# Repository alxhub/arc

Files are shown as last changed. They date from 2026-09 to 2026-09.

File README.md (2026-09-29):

# ARC — model railroad control

ARC is my hobby ecosystem of model railroad control systems. It is designed as an integrated, full stack system, from the computer running the layout to the boards powering track districts, moving turnouts, and lighting signal masts.

The design emphasizes global processing and specialized boards for dedicated tasks. A layout computer knows the track plan and coordinates the whole railroad, while distributed hardware provides the power, sensing, and local control each task needs. This gives the software a layout-wide view while keeping physical connections close to the equipment they serve.

ARC is designed for evolving and temporary layouts, with plug-and-play operation as a guiding goal. Common capabilities are available throughout the system, so changing the track plan can be an ordinary part of using the railroad. That flexibility goes hand in hand with intelligent control: the computer can use its knowledge of track connections and turnout positions to prepare the hardware for a route.

This repository contains ARC's schematics written in [Stackup](https://github.com/stackup-eda/stackup) and the corresponding KiCad PCB projects. Stackup is another of my projects: a declarative language and toolchain for describing electronic circuits as text. It expresses parts, reusable circuits, connections, and design constraints, checks them together, and exports the result for KiCad. Stackup uses KDL as its file syntax, which is why the schematic sources have a `.kdl` extension.

The architecture and intended system behavior are described below; individual board READMEs cover their roles and design decisions. [Control architecture](CONTROL.md) describes the administrative, operations, control, and field planes, including district policy and PSU authority on loss of communication. [ARC CAN protocol](PROTOCOL.md) defines the wire format and node identity scheme.

## Three levels of control

ARC organizes the layout into three levels:

1. **The layout computer**, usually a Raspberry Pi, knows the track plan, runs the layout, and coordinates its behavior. The ARC HAT connects the Pi to the backbone and provides control of the layout's master contactor.
2. **The ARC-Link backbone** connects primary functional boards, including DCC district drivers and Trackside Hubs, over CAN. These boards typically live together in one or more clusters around the layout and are DIN-rail mountable.
3. **Trackside bus legs** extend from those clusters along the rails. They connect boards that serve a local purpose, such as a signal mast, turnout, servo, or vehicle tag reader.

A **Trackside Hub is a backbone board** that connects these last two levels. It receives commands over ARC-Link and manages up to three separate trackside bus legs, using LIN for local signaling. This arrangement lets the backbone connect clusters of functional hardware while the trackside wiring follows the railroad to individual accessories.

## Power and installation

ARC is designed for industrial DC power supplies: **12 V for N scale** and **15 V for HO scale**, with a particular emphasis on DIN-rail mounted supplies. Primary backbone boards share that mounting approach, making it practical to assemble a cluster of power and control hardware together.

The power architecture distinguishes the supply carried by ARC-Link from the power delivered to the rails and accessories. The supply board switches power onto ARC-Link; district drivers and Trackside Hubs also have their own connections to the layout's supply for their loads. District drivers generate rail power locally from the shared DCC timing signal.

## ARC-Link: the backbone

ARC-Link carries power, CAN communication, and DCC synchronization over **eight-wire Ethernet cable**:

| Conductors | Purpose |
| --- | --- |
| 2 | Backbone power |
| 2 | Backbone ground |
| 2 | CAN differential pair for commands and status |
| 2 | DCC differential pair for synchronized track timing |

Ethernet cable is the wiring medium; ARC-Link uses CAN for communication. The separate DCC pair carries timing, not the traction current delivered to the rails. The supply board normally generates that timing, and district drivers use it to produce their individual DCC outputs.

**Ground loop isolation is a central design priority.** The supply board establishes the backbone's ground reference, and other active backbone boards isolate their local circuits from the link. This separates the backbone reference from local track supply returns and control wiring as the system extends between clusters around the layout.

ARC-Link is distinct from LCC. Support for LCC devices is planned through a dedicated **ARC ↔ LCC bridge**, allowing those devices to participate in the layout alongside ARC hardware.

## The trackside bus

The trackside bus uses **four-wire telephone cable with RJ-11 connectors**. Each leg carries four connections:

| Conductor | Purpose |
| --- | --- |
| Track voltage | The layout's track-voltage supply for local loads |
| 5 V | Low-voltage power |
| Ground | Local power and signaling return |
| LIN | Commands and status for trackside boards |

These legs typically parallel the rails, keeping accessory wiring near the devices it serves. A signal controller can sit near its mast, a turnout controller near its turnout machines, and a tag reader near its separate antenna flex.

Each Trackside Hub manages up to three legs and can switch them independently. Its backbone connection crosses an isolation boundary; the trackside legs share the hub's local power and return.

## A dedicated output for every district

ARC calls a track block a **district** and standardizes on a distinct, independently controlled power feed for each one. The system is optimized for many separate outputs, with district boards providing four, six, or eight outputs per board. This makes each district a unit of power control, sensing, and fault handling.

Every district is designed to include the same core capabilities:

- **Built-in block detection through drive-current sensing.** This detects locomotives, but does not detect resistive wheelsets.
- **Built-in autoreversing.** Each district can reverse its output phase as needed for reversing track arrangements, including advance changes coordinated by the layout computer.
- **Programming-track operation on demand.** Any district can serve as a fully featured programming track when needed, with a separate programming signal and a lower current limit.
- **Independent control and fault reporting.** Each output can be switched and monitored separately, so a fault can be identified and handled at the affected district.

These capabilities are part of the district design rather than separate accessories to add to selected sections. A district's role can change with the layout's needs, including switching between normal running and programming operation.

## Layouts that evolve, control that understands them

Having autoreversing available in every district makes it easier to experiment with the track plan. Add a reversing loop on a whim, and the surrounding districts already have the phase control they need: there is no need to carefully rewire them around a specially designated reversing output. Dedicated district feeds and a controller that knows the revised track plan provide the basis for this plug-and-play approach.

That global picture also enables proactive polarity control. ARC is designed to use the track plan and turnout configurations to align district polarities automatically before wheels cross a boundary and cause a short. The layout computer can coordinate the outputs involved in a route because it knows how those sections connect.

The Kato turntable controller is another example of this intended behavior. As the turntable spins, ARC can use its knowledge of the table's position and connecting tracks to align their polarities automatically. The specialized board operates the turntable, while the layout-wide picture makes coordinated track power possible.

## Backbone boards

| Board | Role |
| --- | --- |
| [ARC-PSU-01](backbone/psu-01/README.md) | Switches power onto ARC-Link and normally generates DCC timing. |
| [ARC-HAT-01](backbone/hat-01/README.md) | Connects a Raspberry Pi to CAN and controls the layout contactor. |
| [ARC-EX-ARC](backbone/ex-arc/README.md) | Connects a CommandStation-EX and its motor shield to ARC. |
| [ARC-TERM-01](backbone/term-01/README.md) | Terminates the CAN and DCC pairs at the end of a run. |
| [ARC-DST-01x4 rev 2](backbone/dst-01x4/README.md) | Drives four independent track districts. |
| [ARC-DST-01x6](backbone/dst-01x6/README.md) | Drives six independent track districts. |
| [ARC-DST-01x8](backbone/dst-01x8/README.md) | Drives eight independent track districts. |
| [ARC-YRD-01x8](backbone/yrd-01x8/README.md) | Controls yard turnouts and signal lamps. |
| [ARC-TRK-HUB-01](backbone/trk-hub-01/README.md) | Bridges backbone CAN to three trackside LIN runs. |

## Trackside boards

| Board | Role |
| --- | --- |
| [ARC-TRK-LED-01](trackside/trk-led-01/README.md) | Drives signal lamps on a LIN run. |
| [ARC-TRK-SRV-01](trackside/trk-srv-01/README.md) | Drives servos, sound, and a signal head. |
| [ARC-TRK-NFC-01](trackside/trk-nfc-01/README.md) | Reads vehicle tags with a separate antenna. |
| [ARC-TRK-ANT-01](trackside/trk-ant-01/README.md) | Provides the reader's flexible track antenna. |
| [ARC-TRK-TRN-01](trackside/trk-trn-01/README.md) | Operates four turnout machines. |
| [ARC-TRK-TBL-01xK](trackside/trk-tbl-01xK/README.md) | Operates a Kato turntable. |

## Firmware

The [Rust firmware workspace](firmware/README.md) uses Embassy. It contains the
shared ARC-Link protocol crate at `firmware/shared/link`, the shared DCC packet
and waveform generator at `firmware/shared/dcc`, the `dst-01` board
crate for x4 rev1/rev2, and the `psu-01` board crate for link power, a
bounded locomotive table, and DCC idle and speed packets. DST rev1 includes the
same transmitter, disabled at boot. PSU and DST rev1 both require
[CAN transmit permission](PROTOCOL.md#dcc-control-message-0x01-grant), retained until
the source restarts. Once the expected layout is good, layoutd selects one master
and grants permission. PSU link power and CAN discovery start independently of DCC.
All current firmware targets also use an Embassy bootloader and a shared
[CAN FD update protocol](PROTOCOL.md#firmware-update-over-can-fd) for staged
application updates.

## Layout software

The first host-side service is [layoutd](services/layoutd/README.md). It owns
retained MQTT facts about track nodes, derives and checks the layout graph
against observed CAN node identities, and publishes overall status. Its CAN interface supports file snapshots and the virtual CAN bus for development
and tests. It selects the DCC master only after all expected hardware is accounted for.

The initial [dispatchd](services/dispatchd/README.md) bridge reads district
status and PSU throttle status from the virtual CAN bus, publishes MQTT state
under `/<layout>/district/` and `/<layout>/loco/`, and converts non-retained
locomotive commands to CAN throttle-set frames. PSU and DST rev1 share the
locomotive table and require the transmit grant assigned by layoutd.

The [virtual CAN lab](sim/README.md) builds the DST-01x4 firmware crate as host
binaries for both board revisions and connects them over a simulated CAN bus.
Its world clock starts paused; tests advance it explicitly so CAN arbitration,
PSU and district timers, DCC delivery, track motion, and current sampling share
the same time. The physical track fixture is separate from layoutd's configured
layout, allowing tests to exercise unknown or incorrect track plans.

## Working with the designs

The boards are composed from reusable Stackup circuits in [`shared/`](shared/). Each board directory keeps its `board.kdl`, supporting Stackup sources, functional README, and KiCad PCB project together.

The designs import the [Stackup parts library](https://github.com/stackup-eda/library), pinned in `manifest.kdl`. For local development, add a `manifest.local.kdl` with a path to a parts checkout:

```kdl
library stackup path="../stackup-parts"
```

Run `stackup check backbone/psu-01/board.kdl` to validate a board. Substitute any other board's `board.kdl` path as needed. Use `--locked` to check against the pinned library commit. Without a local override, the CLI fetches Git libraries into `.stackup/cache/` beside `manifest.kdl`.

Each KiCad PCB has a `.stackup_sch` sidecar pointing to the adjacent `board.kdl`. To sync a closed board with the Stackup KiCad plugin, using KiCad's bundled Python (`STACKUP_KDL` is the path to the Stackup worktree):

```sh
/Applications/KiCad/KiCad.app/Contents/Frameworks/Python.framework/Versions/3.9/bin/python3 \
  "$STACKUP_KDL/kicad-plugin/sync_headless.py" \
  backbone/term-01/term-01.kicad_pcb
```

The PCB layouts retain their routed copper and KiCad project settings. Some newer parts in the district and yard schematics still need placement and routing. A Stackup check or PCB sync is not a DRC or fabrication signoff. The antenna board retains an older footprint table as `fp-lib-table.legacy` for reference; KiCad uses its existing `fp-lib-table`.

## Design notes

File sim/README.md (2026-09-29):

# Virtual CAN lab

This lab runs the actual `psu-01` firmware core and the `dst-01` firmware crate
as host binaries, with one district node for each DST-01x4 revision. The nodes use the shared `link` codec to publish the
Presence and periodic or state-change district status frames in [PROTOCOL.md](../PROTOCOL.md),
receive district configuration frames, and run the same four district
controllers as the embedded build. A portable user-space bus carries CAN IDs and
CAN FD payload bytes between independent processes.

Start a bus and two nodes with Docker Compose:

```sh
docker compose -f sim/compose.yaml up --build
```

Compose starts the clock at zero and leaves it paused. Advance it through the
world control port with `{"op":"advance","milliseconds":100}`; no firmware
timer or CAN batch progresses while it is paused.

Node A builds with `host,rev1` and node B with `host,rev2`. PSU-01 closes the
simulated link switch after its monitor responds and qualifies 15 V. It waits
for a CAN transmit grant before starting the `FF 00 FF` DCC idle stream. Run
layoutd against the virtual CAN bus with all three boards in its retained layout
to select and grant a master. The district nodes validate the packet
bits and each half-bit duration and require both power and recurring packets
before treating the source as ready. Every output remains disabled until
configured over CAN. Logs show identities, peer Presence, and state changes.
The host-only `--network-id` override supports collision
tests.

Run the first automated integration scenario:

```sh
python3 -m sim.scenarios short_recovery
python3 -m sim.scenarios district_config
python3 -m sim.scenarios psu_startup
python3 -m sim.scenarios psu_throttle
python3 -m sim.scenarios moving_loco
python3 -m sim.scenarios phase_bridge
```

Each runner starts an isolated Compose project with the same explicit world
clock, including scenarios that leave the physical track fixture disconnected
from district outputs. The original short-recovery
scenario verifies PSU boots without DCC
permission, explicitly grants PSU using the CAN wire message, and waits for both firmware nodes to
see a peer, configures districts 0 and 1 over CAN, then injects a short into each
revision's district 0,
checks that power is inhibited without disturbing district 1, clears the short,
and waits for normal operation to resume after ten clear probes. It reports the
last observed state and container logs on failure, then tears down its project.
It uses a test-only TCP control port on each host binary; these commands are
not ARC CAN messages and are absent from embedded firmware. The scenarios also
observe status frames on the virtual CAN bus, including windowed current after a
short.
The `district_config` scenario verifies default-disabled outputs, wrong-target
and invalid-state rejection, source-readiness gating, one-output enablement,
programming selection, and explicit disablement.
The `psu_startup` scenario verifies automatic link power, the exact idle packet
and timing, PSU CAN status, district source readiness on both revisions, and
loss of district output after a simulated PSU overvoltage latches the link off.
The `psu_throttle` scenario validates two locomotive entries, immediate CAN
status, idempotent repeat, stale-command rejection, and the DCC speed/stop
packet bytes. Both host and board builds accept valid throttle frames without
an authority exchange; that exchange remains future protocol work.

The `moving_loco` and `phase_bridge` scenarios start a separate physical world from
`sim/world/fixtures/two_districts.json`. This fixture owns actual segment
lengths, endpoint connections and A/B rail mapping, district-output wiring,
and loco placement. It exists independently of `layoutd` and MQTT, so a test
can leave the administrative layout unknown or configure it incorrectly while
the physical system continues to behave. The world receives DCC
packets from the signal bus, passes speed commands only to locos on energized
districts, advances their positions, and gives the DST host current and fault
samples. The scenario checks that CAN current moves from one district to the
other as the loco crosses. A pickup span bridges both outputs near a boundary;
a phase mismatch after accounting for endpoint rail mapping produces a fault
and high current on both powered outputs. `phase_bridge` uses a swapped-rail
fixture and checks that the real DST host controllers trip on both outputs.
Host firmware currently holds phase normal, so automatic phase correction is
not yet exercised.

Run the world outside a scenario with:

```sh
ARC_SIM_WORLD=world:17502 docker compose -f sim/compose.yaml up --build
```

`ARC_SIM_WORLD` connects node A to the physical track fixture;
`ARC_SIM_CAN_CLOCK` puts CAN batches on the world clock; `ARC_SIM_CLOCK`
connects PSU and both DST hosts to that clock. Set `ARC_SIM_CLOCK` for a
separately launched layoutd as well, using `127.0.0.1:17502` from the host.
Runs without `ARC_SIM_WORLD`
use the existing fixed-load district behavior. The world control port is 17502 and accepts one JSON
request per line: `{"op":"status"}`, `{"op":"advance","milliseconds":100}`,
`{"op":"set_turnout","piece":"id","path":"route"}`,
or `{"op":"place","loco":"id","piece":"id","path":"route","offset_mm":10}`.

To exercise collision detection, start the optional third node with a different
UID and node A's ID:

```sh
docker compose -f sim/compose.yaml --profile collision up --build
```

Both nodes with ID `fa5138` report the conflict. Collision recovery is not
implemented.

The CAN transport uses newline-delimited JSON internally; this is not an ARC
wire format. It batches frames for 5 ms and orders each batch by CAN ID for
application tests. In scenario runs the batch boundary is every fifth
logical millisecond, and the clock waits for dispatch before continuing. The
scenario sender uses a test-only queue barrier before advancing time. A separate signal bus broadcasts link power and DCC packets
as their bit sequences and half-bit durations, replaying the latest power
state to nodes that join late. Packet validity and liveness are modeled; analog
edge shape and scheduling jitter are not. CAN acknowledgements, errors, and
bus-off are also not modeled.

The host runner uses an initial board-component model. A DRV8874 model derives
fault and current observations from the applied drive and an injected short;
rev1 uses simulated TCA9534 output, direction, and fault-input registers, while
rev2 uses direct GPIO state. The current and fault behavior is intentionally
coarse. Embedded and host firmware share command decoding and status scheduling;
their HALs remain separate implementations, so hardware register behavior must be
checked against the board design as this model matures.

The physical world has one logical clock, starting at zero. DCC packets, output
samples, status requests, and host scheduling do not advance it. A scenario
advances it explicitly with the `advance` request. Live advances run in 1 ms
ticks. At each tick the clock waits for CAN arbitration when due, PSU firmware,
link-signal delivery, ordered district firmware processes, and every registered
output sample before continuing. This prevents a pickup bridge from being skipped.
PSU power qualification, DCC packet cadence, district source timeout, protection
timers, and current-report windows all use this logical time in world scenarios.
Loco position and world time are repeatable for the same tick-ordered inputs. A valid DCC packet marks
the simulated source active until link power or the signal connection is lost;
the DST host still enforces its own 30 ms packet-liveness timeout using logical
time. Socket and process deadlines only detect stalled participants; they do
not advance simulation time. Scripted fault injection remains future work. The model does not resolve electrical waveform
shape, wheel-by-wheel pickup, inertia, or detailed motor physics.

Run portable simulator tests with:

```sh
python3 -m unittest discover -s sim/tests
cd firmware && cargo test -p link && cargo test -p dst-01 --lib && cargo test -p psu-01 --lib
```

PSU and DST rev1 use the shared boot-lifetime DCC permission latch. Both start
without permission; tests use the actual CAN Grant message. Rev2 ignores grants. Source status
reports capability, permission, and actual output. Power loss inhibits output
without clearing permission; source restart clears permission and the table.

The host-process test starts both DST revisions without a PSU, supplies simulated
link power and a logical clock participant, and checks CAN grant targeting, malformed grants, rev2 rejection,
exact idle packets and half-bit timing, and permission surviving power loss.
Build and run it from the repository root:

```sh
(cd firmware && cargo build -p dst-01 --bin dst-01-host --features x4,host,rev1 --target-dir target/host-rev1)
(cd firmware && cargo build -p dst-01 --bin dst-01-host --features x4,host,rev2 --target-dir target/host-rev2)
ARC_DST_REV1_BIN="$PWD/firmware/target/host-rev1/debug/dst-01-host" \
ARC_DST_REV2_BIN="$PWD/firmware/target/host-rev2/debug/dst-01-host" \
python3 -m unittest sim.tests.test_dst_sync
```

The layoutd integration test runs the real daemon with an isolated Docker MQTT
broker and all three host firmware processes. It checks that an absent expected
board blocks permission, completing the layout selects only PSU, layoutd exit
does not revoke permission, and a source restart clears it. Docker must be running.

```sh
(cd services/layoutd && cargo build)
(cd firmware && cargo build -p psu-01 --bin psu-01-host --features host)
ARC_LAYOUTD_BIN="$PWD/services/layoutd/target/debug/layoutd" \
ARC_PSU_BIN="$PWD/firmware/target/debug/psu-01-host" \
ARC_DST_REV1_BIN="$PWD/firmware/target/host-rev1/debug/dst-01-host" \
ARC_DST_REV2_BIN="$PWD/firmware/target/host-rev2/debug/dst-01-host" \
python3 -m unittest discover -s sim/tests
```

The shared `dcc` tests cover packet encoding, table scheduling, continuous bit
sequencing, and permission lifetime. Timer register behavior, interrupt deadlines,
oscillator tolerance, and physical transceiver timing still need hardware checks.
The current signal bus models packet content and liveness, not electrical driver
contention.

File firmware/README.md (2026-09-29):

# ARC firmware

Rust 2024 with Embassy. Run the commands below from this directory; Cargo loads
the aliases and linker settings from `.cargo/config.toml` here.

- `shared/link` (`link`): `no_std` backbone CAN protocol crate, shared by boards
  and host tools. The [protocol specification](../PROTOCOL.md) defines identity
  and Presence; the identity derivation, Presence, district configuration, and
  district status codecs are implemented.
- `shared/dcc` (`dcc`): `no_std` packet encoder, throttle table, continuous bit
  engine, and optional STM32 timer transmitter shared by PSU and DST rev1.
- `dst-01`: district-board firmware. The only variant is `x4`; select exactly one
  of `rev1` and `rev2`. The orthogonal `host` feature builds the same firmware
  crate as a host process for the [virtual CAN lab](../sim/README.md). There is
  no default hardware selection.
- `psu-01`: STM32C092 firmware for automatic ARC-Link power startup, supervised
  INA226 measurements, DCC idle and 128-step locomotive packets, a bounded
  locomotive table, and CAN Presence/status.
- `arc-boot`: Embassy bootloader for the G0B1 and C092 application partitions.

```sh
cargo build-dst-rev1 --release
cargo build-dst-rev2 --release
cargo build-psu
cargo build-boot-g0b1
cargo build-boot-c092
cargo test -p link
cargo test -p dcc
cargo test -p dst-01 --lib
cargo test -p psu-01 --lib
cargo fmt --all --check
```

The build aliases expand to `cargo build -p dst-01 --target thumbv6m-none-eabi
--no-default-features --features x4,rev1` (or `x4,rev2`). Both MCUs use this target;
the revision feature selects the Embassy chip and its generated linker memory
map. Build revisions separately: `--all-features` cannot represent one board.
Each build writes `target/thumbv6m-none-eabi/release/dst-01`, replacing the previous
revision's artifact. Use `--target-dir target/rev1` or `target/rev2` to retain both.

The workspace default member is `link`, so plain `cargo build` and `cargo test`
work on the host. The toolchain file pins Rust and installs the embedded target.
Commit `Cargo.lock` to keep firmware dependencies reproducible.

### CAN firmware updates

All three embedded targets accept the same [CAN FD firmware update
protocol](../PROTOCOL.md#firmware-update-over-can-fd). It uses Embassy's
`embassy-boot-stm32` bootloader and blocking firmware updater. Bootloader and
application builds now have separate flash regions:

| MCU | Bootloader | Active application | Staging | Boot state |
| --- | --- | --- | --- | --- |
| STM32G0B1RE (DST rev1) | `0x08000000`, 16 KiB | `0x08004000`, 240 KiB | `0x08040000`, 248 KiB | `0x0807e000`, 8 KiB |
| STM32C092CB (DST rev2, PSU) | `0x08000000`, 16 KiB | `0x08004000`, 54 KiB | `0x08011800`, 56 KiB | `0x0801f800`, 2 KiB |

Provision each board once with the appropriate `arc-boot` image at the start
of flash and its board application at `0x08004000`. Existing applications linked
at `0x08000000` need this initial reflash through SWD or the available ROM USB
DFU route. The C092 bootloader binary is shared by DST rev2 and PSU. Keep
bootloader and application build artifacts separate with `--target-dir`, as
revision builds otherwise overwrite the previous artifact. Convert the
application ELF to a raw `.bin` with `llvm-objcopy -O binary` before transfer.
Rev1 reserves the last 16 bytes of RAM for the USB console's ROM bootloader
request; the ARC bootloader consumes that marker before starting the application.
The linker partition symbols are offsets from the start of flash, as required
by Embassy's flash driver; the physical image addresses in the table remain
absolute. The initial-image packager checks those symbols in both ELFs and
rejects an image built with the earlier absolute-address layout.

#### Initial rev1 USB provisioning

A factory-blank G0B1 enters the STM32 system-memory loader through its empty
flash check. With the board powered and USB-C connected to a data-capable host,
use STM32CubeProgrammer's USB/DFU connection. Build and package both images from
this directory:

```sh
cargo build-boot-g0b1 --target-dir target/boot-g0b1
cargo build-dst-rev1 --release --target-dir target/dst-rev1
python3 tools/prepare_initial_rev1.py \
  target/boot-g0b1/thumbv6m-none-eabi/release/arc-boot \
  target/dst-rev1/thumbv6m-none-eabi/release/dst-01 \
  target/provision-rev1
```

Program `target/provision-rev1/dst-rev1-initial.bin` as a **binary** at
`0x08000000`, with verify enabled. This single image includes the Embassy
bootloader at `0x08000000` and the rev1 application at `0x08004000`; the staging
and state partitions stay erased. For CubeProgrammer CLI, the equivalent is
`STM32_Programmer_CLI -c port=usb1 -w target/provision-rev1/dst-rev1-initial.bin 0x08000000 -v`.
Power-cycle after a successful verify so the G0B1 rechecks the formerly empty
flash, then look for the ARC USB CDC console. Keep ARC-Link and district loads
disconnected for this first boot. The application ELF has an ELF-header load
segment below `0x08004000`; program the packaged binary, not that ELF directly.
On rev1, the application blinks the RGB status LED through red, green, blue,
yellow, cyan, magenta, and white. The separate green LED on MCU pin 38 (PC6)
blinks with each color; each color and dark interval lasts 300 ms. These LEDs
are an early sign that the application scheduler is running, before checking USB.
For a later application-only flash, enter ROM DFU with `bootloader`, program
`target/provision-rev1/dst-rev1.bin` as a binary at `0x08004000` with verify,
then power-cycle. This preserves the ARC bootloader at `0x08000000`.
On board #2, the RGB green channel was not visibly lighting during initial
bring-up. Its programmed GPIO is PD9 (MCU pin 41), and the rev1 PCB routes it
through R40 (300 Ω) to D3's green cathode. R40's MCU side was observed
alternating between 0 V and 3.3 V with the initial push-pull build. The LED
outputs now use open drain so their off state is high impedance; that change
has not yet been flashed onto board #2. Check R40's LED side and D3 if green
remains dark after the update.
Board #1 was recovered by erasing flash over an ESP32-driven SWD connection,
then reflashed with the open-drain build. Its small green D4 blinks, but RGB D3
is dark; D4 and D3 have separate supply rails, so the RGB lamp rail needs a
voltage check. D3 pad 4 measured about 4.5 V on board #1, so the rail reaches
the LED footprint. A meter-provided ground path at the RGB resistors lit red
and blue but not green; the normal GPIO sink paths have not yet been measured.

On a Linux host with a configured CAN FD SocketCAN interface, run:

```sh
python3 tools/can_update.py --interface can0 --sender-id 000001 \
  --target-id fa5138 --kind dst-rev1 path/to/dst-01.bin
```

Select `dst-rev2` or `psu` for the other applications, and use the target's
actual Presence network ID. The sender ID must be unique on the bus; `000001`
is the virtual lab's configured host identity. The tool checks the image's
stack and reset vectors before sending, then waits for an acknowledgement of
each chunk. The board checks staged flash and lets Embassy swap or roll back
the image. Bench validation of flash swapping and recovery on real hardware
is still required.

`dst-01` now starts four district tasks behind a revision-specific HAL. Its library
contains the hardware-independent configuration and recovery controller, tested on
the host with `cargo test -p dst-01 --lib`. The binary supplies rev1 expander/GPIO
or rev2 GPIO adapters and shared ADC access. Both builds initialize FDCAN1,
publish Presence and district status, and accept targeted district commands.
The CAN pins and interrupts are revision-specific; frame handling and status
scheduling live in `dst-01/src/network.rs`. Rev1 uses its 40 MHz external oscillator for system and CAN timing; rev2
still uses the internal default clock. Rev1 boot, LED heartbeat, and USB CDC
enumeration have been observed on board #2; CAN and district operation still
need hardware validation. Rev2 has not been tested on hardware.

The `dst-01-host` binary runs the same district controller with host-side board
models selected by `rev1` or `rev2`, publishes Presence and periodic or state-change status, and
receives district configuration over the simulated CAN bus. All outputs start
disabled. Its required `--clock` argument connects it to the simulator's
logical world clock; firmware timers do not follow elapsed wall time. The `host`
feature does not select a revision; build it with `x4,host,rev1`
or `x4,host,rev2`. See the [simulation lab](../sim/README.md) for the component
model and its current limits.

On embedded targets, callers submit a complete validated configuration with
`dst_01::tasks::DISTRICTS[index].configure(config)` and read its applied state with
`status()`. CAN commands feed the same latest-value configuration mailbox. The DCC receiver and
programming generator will publish `tasks::Sources` through `tasks::SOURCES`;
neither source is ready at startup, so configuration alone cannot energize rails.
The embedded ADC path currently reports only an overcurrent threshold. Status
frames mark current measurement invalid and set average and peak to zero until
calibrated sampling is implemented.
PSU and DST rev1 use the same `dcc::Permission` latch. A targeted CAN DCC Grant
sets it until MCU restart; duplicate grants are harmless. Both start with DCC
disabled. Power qualification gates actual output without clearing permission.
Rev1 uses TIM14/PC12 and PC13 driver-enable, with active-low link-good on PC2.
CAN capability/permission status lets layoutd choose a master; rev2 reports no
transmitter and ignores grants. Preparing throttle entries never enables DCC.
TX generation does not set receiver readiness or enable any district.

### Rev1 USB debug console

Rev1 exposes a USB CDC serial port on PA11/PA12. Open it with a terminal using
newline-terminated ASCII commands (the baud rate setting is ignored):

| Command | Effect |
| --- | --- |
| `help` | List commands. |
| `led <auto\|off\|red\|green\|blue\|white>` | Resume the RGB blink or hold the selected color for DC measurements. The small green LED follows the selected color. |
| `gpio` | Report the LED pins' GPIO mode, open-drain bit, output sink latch, and sensed input level. A floating off pin's sensed level is not a reliable voltage measurement. |
| `master` | Grant this board DCC transmit permission for this boot. The link-good interlock still gates the driver. |
| `throttle <address> <f\|r> <speed>` | Set a short (1–127) or long (128–10239) locomotive address, forward or reverse, at speed 0–126. |
| `current <ms>` | Log nominal milliamps for all four districts at this interval; `current 0` stops logging. |
| `status` | Show each district's state, trip flag, nominal milliamps, and latest ADC count. State changes are also printed automatically while connected. |
| `bootloader` | Reset directly into the STM32 system-memory USB DFU bootloader for flashing. |
| `erase` | Erase the 2 KiB flash page at `0x08000000` and reset into STM32 ROM USB DFU. This removes the ARC bootloader until it is reflashed. |

The console's local `master` command is for bench debugging and bypasses CAN
master selection; it does not bypass link power qualification. USB descriptors
currently use provisional VID/PID `1209:a0c1`. The ROM bootloader uses its own
USB identity, so the CDC port disappears after `bootloader` and the board must
be flashed through a DFU tool. Rev1 USB CDC, the `bootloader` ROM handoff,
CubeProgrammer DFU detection, and the power-cycle return to the application
have been observed on board #2. The `erase` command has not been validated on
a physical board.
`erase` uses the G0B1 empty-flash boot check. After erasing page 0, firmware
also sets `FLASH_ACR.EMPTY` so a software reset enters ROM. To restore normal
boot, program the ARC bootloader at `0x08000000` and the application at
`0x08004000`, then reload option bytes or power-cycle to update the empty check.
The `bootloader` command leaves flash intact; `erase` is for reinstalling the
bootloader itself. If `BOOT_LOCK` forces boot from main flash, `erase` reports
an error and leaves page 0 intact. The erase path also needs validation on rev1
hardware.

Rev1 current conversion uses the preserved rev1 schematic: 2.21 kΩ at IPROPI
in running mode, 22.1 kΩ in programming mode, no ADC divider, nominal 3.3 V
ADC reference, and the DRV8874's typical 450 µA/A current mirror. The displayed
milliamps are nominal estimates from the latest ADC sample. Mirror error,
resistor tolerance, and ADC reference error remain until bench calibration;
the DRV8874 specifies up to ±30 mA mirror offset below 0.4 A. The console uses
the configured district mode to select the scale.

The shared task operates only through `district::DistrictHal`, leaving revision
details in `dst-01/src/hal/rev1.rs` and `rev2.rs`.

`psu-01` uses the board's 40 MHz external oscillator, TIM3 on PB4 for the DCC
waveform, and an INA226 on I2C1 to qualify the switched ARC-Link rail.
Firmware raises LINK_EN after the monitor responds and enables the CAN
transceiver after a 20 ms supervised link trial in the 12–18 V range and at
no more than 2 A. The DCC driver additionally requires the CAN grant. A bad measurement latches the link off until reset. The
16-entry locomotive table accepts complete throttle commands, emits immediate
and periodic CAN throttle status, and cycles 128-step DCC packets with an idle
packet between rounds. The host and board use the same table and packet rules.
Command sessions scope sequence numbers but do not grant authority. Transmit permission lasts until restart; sender authentication is not implemented.
This image has been compiled but not tested on a real board.
The `psu-01-host` binary runs the same power controller and packet source
in the [simulator](../sim/README.md) and also requires `--clock`. Its signal bus emits each DCC packet's
bits and half-bit durations; district host binaries validate that stream to
decide when their synchronized source is ready.

See the [board README](../backbone/dst-01x4/README.md) for revision hardware and
source references. The shared protocol crate deliberately has no STM32 or
executor dependency.

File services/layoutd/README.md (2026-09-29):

# layoutd

`layoutd` owns retained facts at `/<prefix>/layout/node/<id>/fact`. Each fact
describes one track node: its kind, physical board/output binding, and named
connections to other track nodes. It derives and validates the layout graph by
joining these facts. There is no layout configuration file or retained full
layout object.

The retained `/<prefix>/layout/index` is a JSON array of node IDs. It tells
`layoutd` and other subscribers which retained facts to expect. It contains no
topology or version. On startup, `layoutd` waits for every indexed fact,
rebuilds the graph, checks CAN observations, and republishes overall status.
CAN discovery adds observed hardware nodes to the live picture; an observed
board without a matching binding remains unconfigured and prevents `good`.

Each update publishes `updating`, the retained node facts, the ID list, and then
`good`, `invalid`, or `degraded`. Removing a node clears its retained fact and
omits its ID from the list. An interrupted update may leave mixed old and new
facts; this design favors a small, editable layout over automatic transaction
recovery. The status has a retained offline last will. On a fresh broker, the
daemon waits briefly for an index before accepting the first command; the wait
is not used to certify a populated layout as complete.

The `CanNetwork` trait supplies observations and targeted DCC grants. Use
`tcp://host:port` for the virtual CAN bus, or a JSON snapshot for file-based tests.
The file backend appends grant frames to the sibling `*.commands.jsonl` file;
it does not invent an acknowledgement. SocketCAN remains unimplemented.

After the layout is `good` and every observed board has reported its DCC
capability, layoutd selects one master: an already-permitted source first,
otherwise PSU before DST rev1, then lowest network ID. It publishes the selected
six-digit ID at `/<prefix>/layout/dcc_master` (initially JSON `null`) and sends
CAN grants until permission is reported. That retained value is the selection,
not an acknowledgement. The selected node stays fixed; no handover or failover
is performed. Firmware permission persists until source restart without renewal.
If that source restarts, layoutd can re-grant it when the layout is good again.

An expected board without track outputs, such as PSU, uses an `infrastructure`
node fact with configured empty connections and a binding to board output `0`.
All expected boards, including PSU, must be represented; unexpected observations
still prevent `good`. Capability `kind` is 0 (none), 1 (PSU), or 2 (DST rev1).

Run a local MQTT broker, then start the daemon:

```sh
cargo run --manifest-path services/layoutd/Cargo.toml -- \
  demo services/layoutd/examples/sim-can.json
```

Send a non-retained command to create an isolated district:

```sh
mosquitto_pub -t /demo/layout/command/set -m '{"request_id":"init","id":"main","fact":{"kind":"district","topology":{"status":"configured","connections":[]},"binding":{"node_id":"fa5138","output":0}}}'
```

The daemon publishes a non-retained result at
`/<prefix>/layout/command/result`. A null `fact` removes that node. Adding a connection
requires reciprocal port records on both nodes before overall status becomes
`good`. The simulator file represents CAN observations only. The optional third
and fourth daemon arguments set MQTT host and port.

For host firmware on the CAN lab:

```sh
ARC_SIM_CLOCK=127.0.0.1:17502 \
  cargo run --manifest-path services/layoutd/Cargo.toml -- demo tcp://127.0.0.1:17500
```

With `ARC_SIM_CLOCK`, layoutd participates in the simulator's explicit world
ticks. CAN presence expiry, source expiry, bootstrap timeout, and master
selection use logical milliseconds. The simulator waits for layoutd to process
each tick before advancing. Broker connection deadlines still protect the
socket; they do not move logical time. Omit this variable when running without
the world service.

For example, an expected PSU fact is:

```json
{"kind":"infrastructure","topology":{"status":"configured","connections":[]},"binding":{"node_id":"123456","output":0}}
```

Its node ID must be included in the retained layout index just like district
facts. A `good` layout with no transmitter remains without a selected DCC master.

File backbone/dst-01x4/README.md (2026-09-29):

# ARC-DST-01x4 rev 2

ARC-DST-01x4 drives four track districts. It receives the shared DCC timing signal from the ARC backbone, then lets the controller set each district's phase and turn each output on or off independently. A district can also switch to a separate programming signal with a lower current limit.

The board has its own connection to the layout's track supply. It reports total track current and supply voltage to the controller, while each district reports its own current and fault state. That lets the system identify and respond to a problem in one section without treating all four sections as one output.

CAN connects the board to the rest of ARC for commands and status. The backbone's electrical isolation keeps its return separate from the track supply return. Board and district lights show status locally; a temperature sensor and fan support operation under load.

[Board design](board.kdl)
[PCB layout](dst-01x4.kicad_pcb)

## Firmware revisions

The Embassy firmware crate is [`firmware/dst-01`](../../firmware/dst-01), with
the `x4` variant feature and exactly one hardware revision feature:

| Feature | MCU | District control |
| --- | --- | --- |
| `rev1` | STM32G0B1RE | Two TCA9534 I/O expanders at `0x20` and `0x21`, on I²C3 (PC0 SCL / PC1 SDA) |
| `rev2` | STM32C092CB | Direct MCU GPIO, as described in the adjacent KDL sources |

Rev1's expanders carry phase, programming selection, sleep, and fault signals;
its PWM gates and analog sense inputs connect directly to the MCU. Rev1 is still
a firmware build target even though its Stackup design toolchain is retired.
Its reference is `pre-kdl-local`: the preserved firmware pin map is
`firmware/dst-01x4/src/pins/mk1_rev1.rs`, and the hardware source immediately before
commit `b27db1e` describes rev1. The branch tip's hardware source already describes
rev2, so it must not be used as the rev1 pin map.

Rev1 also has a backbone DCC transmitter: TIM14 channel 1 on PC12 (AF2), with
PC13 controlling driver-enable. Firmware uses the shared `dcc` crate for idle and
128-step speed packets and the timer waveform, clocked from the board's 40 MHz
oscillator. TIM3 remains reserved for Embassy time. The transmitter initializes
disabled and accepts the same [CAN transmit grant](../../PROTOCOL.md#dcc-control-message-0x01-grant)
as PSU. Permission persists until MCU restart. The active-low link-good input
on PC2 gates actual transmission without clearing permission.
Generation alone does not mark the received source ready or enable districts.
Rev2 has no corresponding transmitter support.

Rev1 routes USB D−/D+ to PA11/PA12. Firmware presents a CDC debug console for
local DCC master and throttle commands, district state transitions, nominal
current logging, reboot to the STM32 ROM USB DFU bootloader, and an `erase`
command that clears the first flash page for bootloader replacement. See the
[console command reference](../../firmware/README.md#rev1-usb-debug-console).

Rev1's small green D4 uses `logic/brick/+`. Its RGB D3 uses the separate
`indicator/lamp_rail/+`, supplied by U25 from `VPWR` and connected to D3 pad 4.
During bring-up, board #1 ran the LED task and blinked D4 but did not light D3;
D3 pad 4 measured about 4.5 V, so the lamp rail is reaching D3. The remaining
checks are the PC7/PD9/PD8 sinks through R39/R40/R41 and D3's solder joints or
orientation. On board #1, grounding the RGB resistor paths with a meter lit
red and blue but not green. This suggests the red and blue dies and their common
anode can conduct, while their normal GPIO sink path still needs checking;
green may have a separate resistor, joint, or die fault.

See [firmware build instructions](../../firmware/README.md).

## District tasks and recovery

Firmware starts one Embassy task per district. Each owns its active configuration,
hardware handle, and recovery state. `Disabled`, `Synced`, and `Programming` select
whether the district is off or takes the backbone or programming stream. All
districts boot disabled. A separate source-readiness interlock must also allow the
selected stream; the DCC receiver and programming generator have not yet been
implemented, so both readiness flags currently stay false and the rails stay off.

The task uses a `DistrictHal` abstraction. Rev1 serializes access to its two
expanders, preserving the other district's output bits; rev2 uses direct GPIO.
The implementations handle the opposite programming-select polarities (rev1
active high, rev2 active low). Both read ADC current sense and active-low fault
signals, and both can inhibit the district through a direct MCU gate without
waiting for I²C. Source/range changes happen with the gate off. Phase is held
normal; autoreversing is not implemented yet.

Short recovery limits average delivered energy with **burst duty limiting**:
short powered probes separated by unpowered intervals, rather than high-frequency
PWM over the DCC signal. The initial policy is:

- A probe is nominally 2 ms on, followed by at least 40 ms off (about 4.8% duty).
- A bad powered sample immediately ends the probe or continuous drive. The off
  interval doubles after each failed probe, up to 10 seconds.
- Ten consecutive clear probes restore continuous drive. Readings taken while
  off never count as clearance. Startup also passes through these probes.
- Five seconds of healthy continuous operation resets the backoff. Configuration
  changes and disabling/re-enabling cannot erase accumulated short backoff.
- Hardware I/O errors latch that district off. An explicit disabled configuration
  clears the latch; a subsequent enabled configuration starts recovery again.

These timings are local firmware policy, with nominal retry duty at or below
10%. The backoff follows the approach in CommandStation-EX's
`MotorDriver::checkPowerOverload`; its fault-ignore delays and brake PWM are not
ported. The first millisecond of each probe allows driver wake-up and sense-filter
settling. Software trips at 90% of the nominal analog trip-reference voltage:
ADC counts 3334 on rev1 and 2780 on rev2, for either current range. These are
initial engineering thresholds, not calibrated current measurements.

The tasks poll at approximately 1 ms intervals. Shared-bus transactions and
scheduling add latency, so probe durations and duty ratios are nominal, not
hardware-enforced bounds. The DRV8874's local current limiting remains necessary.
Bench validation of thresholds, wake-up timing, short energy, and recovery with
real loads is still required. TIM3 currently supplies Embassy time and must be
reassigned before using it for rev2's pixel stream. The [district configuration
CAN message](../../PROTOCOL.md#district-control-message-0x01-configuration) and
periodic and state-change [status message](../../PROTOCOL.md#district-status-message-0x01-status)
are wired to FDCAN1 on both revisions and exercised in the virtual CAN lab.
Hardware CAN validation, calibrated current measurement,
DCC source readiness, programming generation, and autoreversing remain pending.

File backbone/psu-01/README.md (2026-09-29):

# ARC-PSU-01

ARC-PSU-01 supplies the ARC backbone. It takes power from the layout's track supply and switches it onto the cable that serves the other ARC nodes. The switch is off during reset. Firmware closes it automatically after the INA226 monitor responds, then checks the downstream voltage and current before enabling CAN. The DCC line driver also requires a CAN transmit grant. A failed reading or out-of-range voltage/current latches the link off until reset. No CAN command is needed to power the link.

This board is also the usual source of the shared DCC timing signal. It sends that signal to track drivers while CAN carries commands and status between boards. It monitors the power sent onto the backbone and has a light bar for local status.

The firmware repeats a DCC idle packet (`FF 00 FF`) once link power is qualified and layoutd grants transmit permission. Its TIM3 output is driven at 58 µs per half-bit for a `1` and 100 µs per half-bit for a `0`; the line driver stays disabled until both the link reading and transmit permission allow it. A bounded 16-locomotive table cycles 128-step speed packets with an idle packet between rounds and reports each applied state on CAN when it changes and periodically. The board and host simulator both accept valid locomotive throttle frames and send their DCC packets. Command sessions scope sequence numbers; the shared DCC transmit grant persists until MCU restart, without renewal or revocation. DCC readback, console diagnostics, and the light bar also remain to be implemented. DCC timing and fault response still need board-level measurement.

The supply node establishes the backbone's ground reference. Other ARC backbone nodes connect through isolation. A separate USB console provides local diagnostics and setup.

[Board design](board.kdl)
[PCB layout](psu-01.kicad_pcb)

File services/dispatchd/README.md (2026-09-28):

# dispatchd: first bridge slice

`dispatchd` reads district and PSU throttle status from the simulator CAN bus,
publishes operational MQTT state, and translates complete locomotive throttle
commands to ARC-Link CAN. The PSU maintains a locomotive table and reports
its applied state, so `active` is populated after a fresh PSU status arrives.
This service does not yet manage control ownership, warrants, or authority
grants.

Run against the virtual CAN bus and an MQTT broker:

```sh
cargo run --manifest-path services/dispatchd/Cargo.toml -- \
  services/dispatchd/examples/demo.json 127.0.0.1:17500
```

The optional third and fourth arguments are MQTT host and port. `sender_id` is
a configured 24-bit CAN source ID for this initial simulation. Pi identity and
collision recovery remain protocol work. `session` scopes command sequence
numbers and is not an authority grant.
`occupancy_threshold_ma` is a provisional average-current threshold for a
running district; it needs calibration. Non-running or invalid sensing yields
`unknown`, and a three-second status timeout emits an `unknown` update.

Publish a non-retained command:

```sh
mosquitto_pub -t /demo/loco/test/command -m \
  '{"type":"throttle","request_id":"r1","target":{"direction":"forward","speed":20,"stop_mode":"normal"}}'
```

`/demo/loco/test/throttle` is retained and contains exactly `target` and
`active`. `target` is the last accepted complete throttle request; `active` is
the latest fresh PSU status block, or `null`. The status block carries
`observed_at_ms`; clients must age it out if `dispatchd` disconnects before it
can clear its retained snapshot. CAN transmission is not PSU
acceptance. `/demo/loco/test/result` is a non-retained local validation/send
result. Incoming commands are never retained; retained commands are ignored.

`/demo/district/<board-id>-<n>/status` is non-retained, where the board ID is
six lowercase hex digits and `n` is 1–4. It reports `occupancy` as `occupied`,
`clear`, or `unknown`, together with district mode, controller state, current
validity, average/peak current, measurement window, and protection trip. The
MQTT suffix is one-based; the CAN output index is zero-based.

The simulator bus is a TCP line transport for CAN frames. SocketCAN access,
PSU command acceptance, source identity, control handover, and authority
sessions are subsequent integration steps.

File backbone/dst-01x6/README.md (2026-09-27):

# ARC-DST-01x6

ARC-DST-01x6 drives six independent track districts from the layout's track supply. It receives DCC timing over the ARC backbone, while CAN carries commands and reports each district's state.

Each district can drive normal train traffic or a programming track at a lower current limit. The board measures its total track current and each district's current, so ARC can identify an overloaded section. Two temperature sensors and a controlled fan support sustained operation.

The six district board serves larger sections of a layout with one controller and one backbone connection. Its link is electrically isolated from the track supply, and its DC input protects against a reversed field connection.

[Board design](board.kdl)
[PCB layout](dst-01x6.kicad_pcb)

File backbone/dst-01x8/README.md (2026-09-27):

# ARC-DST-01x8

ARC-DST-01x8 drives eight independent track districts from the layout's track supply. It receives the shared DCC timing signal over the ARC backbone and uses CAN for commands and status.

Each district can switch between running trains and a lower current programming mode. The controller receives a separate fault and current measurement from every district, plus a measurement of total track current. Two temperature sensors watch the board's two groups of four districts.

This board lets a larger area of a layout share one controller and backbone connection while keeping its track outputs independent. Its backbone connection is electrically isolated from the track supply, and its DC input protects against a reversed field connection.

[Board design](board.kdl)
[PCB layout](dst-01x8.kicad_pcb)

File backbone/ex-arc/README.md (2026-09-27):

# ARC-EX-ARC

ARC-EX-ARC fits between a CommandStation-EX CSB1 and its motor shield. It lets the command station join ARC's CAN backbone and share its DCC timing with other districts. When the CSB1 acts as a booster, the board can feed it the backbone's DCC timing instead.

A small controller handles backbone communication, selects the booster input, and watches the motor shield's fault outputs. It can brake either track channel locally and tell the CSB1 what happened over a dedicated UART.

[Board design](board.kdl)
[PCB layout](ex-arc.kicad_pcb)

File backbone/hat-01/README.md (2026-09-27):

# ARC-HAT-01

ARC-HAT-01 connects a Raspberry Pi to an ARC layout. It powers the Pi from the cabinet's control supply, gives Linux a CAN interface to the backbone, and lets the Pi listen to DCC timing. The Pi controls the layout's master contactor and reads its auxiliary contact to learn whether the contactor closed.

The HAT also exposes the Pi's I²C bus on a Qwiic connector. It keeps the backbone electrically isolated from the Pi and cabinet control wiring.

[Board design](board.kdl)
[PCB layout](hat-01.kicad_pcb)

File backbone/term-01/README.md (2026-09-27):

# ARC-TERM-01

ARC-TERM-01 closes the end of an ARC backbone run. It terminates both the CAN connection used for commands and status and the DCC timing connection used by track drivers. A run uses a terminator at each end; the nodes along it pass the connections through.

The board has one backbone jack. A power light shows whether the backbone supply reaches this end of the run, and measurement points give installers a place to check the supply and both signal pairs.

[Board design](board.kdl)
[PCB layout](term-01.kicad_pcb)

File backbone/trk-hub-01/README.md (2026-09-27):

# ARC-TRK-HUB-01

ARC-TRK-HUB-01 connects the ARC backbone to trackside devices. It receives commands over CAN and manages three separate LIN runs. Each run can serve signal and accessory nodes along the track and can be switched independently.

The hub has its own connection to the layout's supply. It measures the power sent down its LIN runs, so the controller can see their combined load. A status light and an expansion port are available at the hub.

The CAN backbone crosses an electrical isolation boundary here. The shorter LIN runs share the hub's local power and return.

[Board design](board.kdl)
[PCB layout](trk-hub-01.kicad_pcb)

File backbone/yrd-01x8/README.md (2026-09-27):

# ARC-YRD-01x8

ARC-YRD-01x8 controls eight turnout machines and sixteen signal lamps from one ARC node. CAN carries commands over the backbone. The board distributes those commands to eight independent machine outputs and an I²C lamp driver.

Each machine channel can throw in either direction and reports its current to the controller. The board sets a shared current limit for the active throw and measures its supply voltage. It supports reversible solenoids and stall motors; a dual-coil machine’s common connects to the cabinet supply return.

The signal header provides sixteen individually dimmable outputs for common-anode lamps. A Qwiic port shares its I²C bus for local accessories. Board status is visible on an RGB lamp, while the separate regulator lamp shows that logic power is present.

[Board design](board.kdl)
[PCB layout](yrd-01x8.kicad_pcb)

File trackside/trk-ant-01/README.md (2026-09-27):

# ARC-TRK-ANT-01

ARC-TRK-ANT-01 is the flexible antenna for an ARC trackside NFC reader. It sits beneath the track and connects to the reader board through a narrow tail. The reader can use it to detect a tagged vehicle passing overhead.

The antenna is copper etched into the flex, with no electronic components to assemble. Its two connections mate with the reader's antenna port.

[Board design](board.kdl)
[PCB layout](trk-ant-01.kicad_pcb)

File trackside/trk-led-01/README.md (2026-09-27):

# ARC-TRK-LED-01

ARC-TRK-LED-01 is a trackside signal node. It connects to a LIN run from an ARC track hub and controls up to twelve signal lamps, arranged as four groups of three. A local pixel output can add an illuminated detail or indicator at the signal.

The hub sends aspect commands; this board turns them into lamp brightness. It reads the supply arriving on the cable so the lamps can keep a consistent appearance when that voltage varies. On startup or after lost communication, the lamps remain dark until the hub commands a state.

It receives its power and communication through the LIN cable. The board also offers a small expansion port for a nearby accessory.

[Board design](board.kdl)
[PCB layout](trk-led-01.kicad_pcb)

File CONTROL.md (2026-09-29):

# ARC control architecture

This document captures the intended responsibilities and interactions of ARC's
control planes. It is an architecture draft, not a description of completed
firmware or a CAN wire-protocol specification. See [README.md](README.md) for
the system's physical organization, [PROTOCOL.md](PROTOCOL.md) for the ARC CAN
wire format, and the board READMEs for implementation status.

## Planes and responsibilities

ARC separates four responsibilities. The layout computer, normally a Raspberry
Pi, hosts both the administrative and operations planes. The CAN network forms
the control plane, and individual nodes form the field plane.

| Plane | Responsibility |
| --- | --- |
| Administrative | Provides interfaces to the outside world; grants control authority and distributes configuration and policy to nodes. |
| Operations | Uses layout-wide knowledge to track locomotives, automate movements, manage throttles, and anticipate conflicts or needed hardware changes. |
| Control | Carries events and coordination over CAN; nodes report and respond according to their configured policies. |
| Field | Owns physical interfaces, sensing, actuation, and local electrical protection. |

These are divisions of responsibility, not separate devices or physical network
tiers. A node participates in the control plane while implementing its physical
behavior in the field plane.

### Administrative plane

The administrative plane establishes what nodes are allowed to do and the bounds
within which they operate. It configures behavior when authority or communication
is lost. Nodes execute that policy without requiring the Pi to referee every
incident.

DCC transmit permission lasts until the source restarts. Operational movement
authority is separate and can have its own lifetime.

### Operations plane

The operations plane holds the layout-wide picture: track connections, turnout
positions, district occupancy, and locomotive movements. It may provide scripted
loco automation and PTC-type services, adjusting throttles or applying brakes
when a locomotive approaches an occupied block, a misaligned switch, or another
conflict.

It can also anticipate actions that nodes would otherwise handle reactively.
For example, the Pi can track a locomotive through reported district occupancy
and request the appropriate output phase before it crosses a reversing-loop
boundary. This improves operation without being required for local electrical
safety. If the prediction is absent or wrong, district protection and permitted
reactive recovery remain responsible for the electrical response.

Movement-conflict protection and electrical protection are distinct. Local short
protection does not replace an operations service that prevents conflicting
movements. The response to loss of operational control is administrative policy;
DCC source permission remains granted until source restart.

### Control plane

Nodes publish events and respond to track observations and CAN events under their
policies. Coordination can occur directly between nodes without a round trip
through the Pi.

District MCUs do not maintain track adjacency or route models. The Pi translates
its layout knowledge into narrower rules for each district: the bounds of its
behavior and how it should respond to specified events. Referencing a CAN event
or another node does not require understanding the physical track relationship
behind that rule.

### Field plane

Each node has ultimate responsibility for electrical safety at its interfaces.
A district node inhibits an output when it detects a short without waiting for
CAN traffic or Pi approval. It may subsequently coordinate over CAN to determine
whether policy permits an autoreversing response and a protected retry.

Administrative authority, operational requests, and peer coordination never
override a local electrical protection constraint.

## Explicit state

State instructions express explicit desired values, never an operation relative
to the receiver's current state. For example:

- Set a district to enabled or disabled; do not toggle it.
- Set phase to normal or inverted; do not command a relative phase flip.
- Set a locomotive's requested throttle state; do not increment its current speed.

Repeating the same state instruction must not repeat a relative action. Events
may describe transitions, but the resulting state instructions remain explicit.

Policy, requested state, and observed state have distinct meanings:

| Kind | Meaning |
| --- | --- |
| Policy | Permitted behavior, constraints, and responses to events or loss of authority. |
| Requested state | The explicit operating state requested by an authorized controller. |
| Observed state | The actual state, including local protection, recovery, and reasons an output is inhibited. |

Acceptance of a request does not imply that an output is delivering power. A
district may have applied a requested mode while waiting for a valid DCC source
or recovering from a fault.

## District behavior and coordination

DST-01x4 presents the same logical district behavior for both hardware revisions.
Revision-specific GPIO, expander access, and signal polarities belong in the
hardware implementation. Hardware revision and capabilities can be reported
without requiring separate control semantics for each revision.

The Pi issues a policy for each district. That policy defines its operating
bounds and its responses to local track events and CAN events. Coordination rules
must settle which participant may change phase and which must hold, avoiding
multiple districts repeatedly reversing together.

A reactive short response follows this division of responsibility:

1. The district detects a fault and locally inhibits its output.
2. The node reports the event and performs any coordination required by policy.
3. If permitted, it applies an explicit phase and conducts a locally protected retry.
4. It reports the resulting state so peers and the Pi can update their observations.

Proactive operations requests and autonomous recovery both feed the district's
decision process. Their precedence must be explicit in policy; competing writers
must not repeatedly undo each other's phase decisions. The precise arbitration
and stale-message rules remain protocol design work.

Pi presence is not itself a prerequisite for district power. A district follows
its policy, source-readiness requirements, and local protection. Loss of Pi
communication, loss of CAN communication, loss of backbone power, and loss of a
valid DCC signal are different conditions, not a single undifferentiated offline
state.

## DCC master and transmit permission

PSU-01 and DST-01 rev1 can be the DCC synchronization master. They share a
locomotive throttle table and packet generator implementation. Each source boots
with an empty table and its DCC line driver disabled. PSU link power and CAN
start independently so all expected boards can be discovered first.

Once layoutd sees a valid layout with every expected hardware node accounted for,
it selects one capable source and sends a targeted CAN transmit grant. It prefers
PSU, then DST rev1, breaking ties by network ID. It reuses an already-granted
source when layoutd itself restarts. The chosen source publishes its capability,
permission, and actual transmit state. Layoutd retains the selected node at
`/<layout>/layout/dcc_master` and retries the same grant until status confirms it.

Permission is latched until the source restarts. It has no lease, renewal,
revocation, handover, or automatic failover. Losing layoutd or CAN does not remove
permission or change the held throttle table. Local power qualification can
inhibit the physical output while permission remains granted. On source restart,
permission and the throttle table are cleared; layoutd may grant the same source
again after the layout is good.

District mode and source readiness remain independent: granting DCC transmission
does not energize any district. Throttle-table commands do not grant transmission.
Movement-authority and stop policies belong to the operations plane; this grant
only chooses which node may drive the backbone DCC pair.

## Pi software services

The Pi software separates administrative configuration, operational state,
traffic planning, movement protection, and command sources. These are distinct
ownership boundaries even when all services run on one Pi.

| Service | Owns | Interfaces |
| --- | --- | --- |
| `layoutd` | Layout topology, district-to-track mappings, administrative policy, and DCC master selection and boot-lifetime transmit grants. | CAN; layout configuration and publication to other services. |
| `dispatchd` | The authoritative operational picture, locomotive control ownership, and translation of permitted requests into track directives. | CAN and MQTT. |
| `routingd` | Journey planning, reservations, passing maneuvers, and traffic flow. | Software service interfaces; movement requests flow through `dispatchd`. |
| `ptcd` | Movement protection and issuance of track warrants. | Consumes the operational picture and publishes warrants over MQTT. |
| `controllerd` | Physical throttle peripherals and throttle protocol sessions, including Stream Deck and WiThrottle interfaces. | Peripheral interfaces and MQTT; no CAN. |
| `automationd` | Script execution, journey intent, and script progress. | MQTT; no CAN. |

`layoutd` supplies the layout definition; `dispatchd` interprets observations
against it. `routingd` and `ptcd` consume the same operational picture rather than
maintaining competing authoritative estimates of train positions. A mapping
change makes earlier operational interpretations stale; consumers must wait for
the layout to return to `good` and rebuild their picture.

The intended benefit is independent evolution of these responsibilities: a new
planner or automation language can use the same movement protection and hardware
interfaces. Separate processes also introduce restart, freshness, and partial
failure cases that their contracts must address.

### CAN access and MQTT

The HAT's CAN controller is exposed to Linux through SocketCAN. Multiple processes
can independently open sockets on the same CAN interface, with matching received
frames delivered to each interested socket. A single userspace process does not
need exclusive ownership of CAN communication. See the
[Linux SocketCAN documentation](https://docs.kernel.org/networking/can.html).

`layoutd` and `dispatchd` have separate reasons to use CAN. Monitoring tools may
also observe traffic independently. Shared access does not confer shared command
authority: discovery, collision handling, and protocol sessions still need
explicit owners. The hardware-independent ARC-Link `link` crate provides the
home for shared message definitions and codecs.

MQTT carries operational requests and published state between services. Requested
throttle state, effective commanded state, and observed physical movement are
distinct. Controllers display the effective result even when it differs from a
request because movement authority restricts it.

The first `dispatchd` MQTT contract uses the layout root directly:
`/<layout>/loco/<id>/command` carries non-retained requests, and
`/<layout>/loco/<id>/throttle` publishes a retained object with `target`
(the accepted requested throttle) and `active` (the fresh PSU-reported DCC
table state, or null). `/<layout>/district/<id>/status` publishes non-retained
district observations. A district ID is the six-digit lowercase CAN board ID,
then `-`, then the one-based output number 1–4; CAN uses output indices 0–3.
Neither an active throttle nor measured current proves physical movement.

`layoutd` is the sole publisher of retained layout facts at
`/<layout>/layout/node/<id>/fact`. Each fact describes one district or turnout,
its named connections, and any physical board/output binding; an unconfigured
entity has an explicit `unknown` topology. `layoutd` derives the graph from these
facts. A retained index is a plain list of node IDs, giving subscribers a way
to know which retained facts to collect; it does not store topology or version
them. CAN discovery contributes observed hardware nodes.
`layoutd` publishes overall `updating` status before changing records, then
publishes `good` only after topology validation, expected CAN node presence,
and broker acknowledgement of the new records. An interrupted update may leave
partially changed facts; recovery can require another explicit update. The index
defines the expected fact set even if status is `invalid` or `degraded`;
consumers require both the indexed facts and the status appropriate to their task.
MQTT publication alone does not prove a subscriber has received them. Loss of a
node or divergence from configured state changes the overall status, and a
retained MQTT last will marks `layoutd` offline on connection loss.

Manual controllers and automation use the same operational request path.
`dispatchd` arbitrates locomotive control ownership and handover so a script and
a throttle cannot silently compete to drive the same locomotive. The PSU remains
the owner of the DCC throttle table and periodic packet generation; `dispatchd`
owns operational intent and tracks the PSU's applied state.

### Traffic planning and movement protection

An automation script expresses a journey such as "move this train from A to B at
speed X." The requested speed is subject to the route and movement authority.
The script does not need to select each turnout or solve conflicts with other
scripts. `routingd` considers competing journeys together and chooses routes,
waiting points, and passing opportunities.

`routingd` manages traffic flow; `ptcd` prevents conflicting authorized movements.
A planned route or reservation is not permission to move. `ptcd` evaluates the
operational picture and issues a track warrant that bounds what `dispatchd` may
command. It is a separate authority issuer, not an inline rewriter of throttle
messages between MQTT and CAN.

When configured to require warrants, `dispatchd` requires both a throttle request
and valid movement authority. A warrant permits movement but does not itself
request motion. It must express constraints `dispatchd` can enforce; the exact
representation of direction, speed, route limits, and braking remains design work.

For two trains approaching in opposite directions, `routingd` may revise a
journey to put one train in a passing siding and hold it while the other passes.
It must account for train extent, siding capacity, and whether the maneuver is
still reachable. Turnout position and clearance must be established before the
corresponding movement is authorized.

Uncommitted plans can change freely. Changes affecting already authorized
movement require a coordinated transition: a revised route cannot throw a turnout
under an approaching train or grant a conflicting movement before the old
authority has been safely withdrawn. If a siding is no longer reachable within
the movement constraints, the planner must choose another meet or hold traffic
elsewhere. A poor plan may cause delay or deadlock; it must not bypass protection.

### Warrants and service failure

Track warrants belong to an identified `ptcd` session. Its MQTT last will revokes
that session's movement authority, allowing `dispatchd` to invalidate all warrants
from that issuer without requiring a separate last-will message for every train.
A restarted issuer must establish fresh authority; retained or delayed messages
from an old session must not restore it.

MQTT last-will delivery depends on broker detection of connection loss and any
configured Will Delay. Normal graceful disconnection suppresses the will, so an
orderly shutdown must explicitly revoke authority. See the
[MQTT 5.0 specification](https://docs.oasis-open.org/mqtt/mqtt/v5.0/mqtt-v5.0.html).

Warrants also need bounded validity enforced locally by `dispatchd`. This covers
undelivered last wills and a stalled protection process whose MQTT connection
remains alive. Renewal must represent continued protection decisions, not merely
transport liveness. Exact timing and freshness rules remain to be specified.

Revoking movement authority actively changes the effective throttle state.
Simply ignoring new throttle requests is insufficient because the PSU keeps
broadcasting its existing table. `dispatchd` commands the stop response selected
by policy. Fresh authority alone must not resume a stale movement request;
recovery requires an explicit fresh request or re-arm.

| Failure | Intended response |
| --- | --- |
| `ptcd` disappears or warrants expire | `dispatchd` invalidates the affected authority and commands the configured stop response. |
| MQTT communication is lost | `dispatchd` applies the configured communication-loss response; local warrant expiry bounds continued permission. |
| `dispatchd` fails | DCC permission remains granted; operational stop policy is separate. |
| Pi or CAN disappears | The selected source keeps its permission and held throttle table until restart. |

`layoutd` readiness controls the initial source assignment. It does not renew
transmit permission or revoke it when operational health changes.

## Operational picture and reconciliation

`dispatchd` builds the operational picture from CAN observations and the layout
definition. It owns train identity association, estimated location and direction,
train extent, and interpreted occupancy. Other services may supply information
or request corrections, but consume `dispatchd`'s published interpretation.

Observations and estimates remain distinguishable. "District 7 draws current"
is an observation. "Train A's locomotive is in district 7 and its tail may still
occupy district 6" is an estimate. The picture must expose uncertainty, freshness,
and the layout version used, including unidentified occupancy and unknown train
locations.

A throttle command or warrant is not evidence of physical movement. Position
updates come from observations and explicitly identified estimates. Locomotive
current detection alone cannot establish that the entire train has cleared a
block; unpowered cars may remain behind. Train extent and braking estimates need
defined inputs and conservative handling of uncertainty.

### Human intervention: the "hand of god"

An operator may pick up a derailed locomotive and place it in another district.
This invalidates the expected movement history. Reconciliation is a normal
operational behavior, not an exceptional repair of the layout database.

The intended automatic response is:

1. A district containing a known locomotive shorts and subsequently returns with
   no detected load. Once valid sensing establishes the disappearance,
   `dispatchd` immediately clears that locomotive's throttle state at the PSU and
   marks its location unknown.
2. Another district draws current without a corresponding plausible arrival of a
   tracked locomotive. `dispatchd` marks the load unidentified and may request
   that the district switch to programming mode to probe locomotive identity.
3. The district executes the identification operation under its policy and local
   electrical protection. A confirmed result lets `dispatchd` reconcile the
   locomotive's location. No response, ambiguous results, and hardware failures
   must remain distinguishable from successful identification.
4. The old journey and movement authority remain suspended pending reassessment.
   Recognition of the locomotive does not restore its previous throttle state.

Zero current while an output is inhibited, cooling down, or missing its DCC source
does not establish disappearance. Occupancy reports need sensing validity and
district state. Likewise, a missing locomotive does not prove its former track
is clear of cars; uncertainty about train extent must remain visible to `ptcd`.

Programming-mode identification is an intended capability, not an implemented
guarantee. The operation must establish suitable conditions rather than assume
an unexplained load is exactly one locomotive or that its district is electrically
separate from neighboring track. Probe eligibility, identification semantics,
and failure handling remain to be designed and validated.

Useful tracking states are tracked, missing, unidentified, and reconciling.
Operator declarations such as "I moved locomotive A here" or "I removed this
train" provide another reconciliation input, with the same stopped-state and
authority reassessment behavior as automatic discovery.

## Remaining protocol decisions

This architecture establishes responsibilities. Further design must define:

- CAN message formats beyond Presence and district control/status, protocol evolution, and collision recovery
  (see [PROTOCOL.md](PROTOCOL.md) for the defined wire format).
- Policy representation and the precedence of operational requests and local recovery.
- Authority sessions, renewal timing, and rejection of stale commands or renewals.
- Peer coordination exchanges, timeouts, and behavior when coordination fails.
- State acknowledgements, event reporting, and periodic status snapshots for other nodes.
- Startup and reset behavior, including policy persistence and PSU throttle initialization.
- MQTT request/state schemas, issuer sessions, warrant validity, and service health contracts.
- Layout change transitions, train extent estimation, and operational-picture freshness.
- Locomotive control handover, journey lifecycle, and coordinated route/authority changes.
- Ownership of turnout execution and locking during route establishment and release.
- Identification-probe eligibility, results, and operator-assisted reconciliation.

These details belong in the Pi service contracts, shared ARC-Link protocol, and board implementations
without moving local electrical protection into the network or requiring district
nodes to understand the layout's track topology.

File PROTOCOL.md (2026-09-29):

# ARC CAN protocol

This document defines the ARC-Link CAN wire space. The defined messages are
Presence, District Configuration, District Status, PSU Status, Locomotive Throttle Set, Locomotive Throttle Status, DCC Grant, DCC Status, and firmware update transfer. Future messages must use the common frame rules below and receive an
explicit class and type assignment here before implementation. The control
responsibilities that these messages serve are described in [CONTROL.md](CONTROL.md).

## Network identity

Every ARC CAN data frame carries the transmitting node's 24-bit network ID in
the low 24 bits of its extended arbitration identifier. Network IDs are written
as exactly six lowercase hexadecimal digits in MQTT, configuration, and
diagnostics, with leading zeroes when needed and no `0x` prefix. A network ID
identifies a board, not an individual district output; an output is identified
by its board ID and output index.

An STM32 node obtains the 12 UID bytes at successive addresses of its MCU's
96-bit unique-device-ID register. Its initial network ID is the low 24 bits of
the 32-bit FNV-1a hash of the five ASCII bytes `stm32`, followed immediately by
those 12 UID bytes in increasing register-address order. There is no separator
or terminator:

```text
hash = 0x811c9dc5
for byte in ASCII("stm32") || uid[0..12]:
    hash = ((hash XOR byte) * 0x01000193) mod 2^32
network_id = hash AND 0x00ffffff
```

For example, UID bytes `00 01 02 03 04 05 06 07 08 09 0a 0b` produce network
ID `fa5138`. The byte order of the UID is defined by its register addresses,
not by the MCU's integer endianness. Both DST-01x4 revisions use this same rule.

A 24-bit hash can collide. Presence carries the full device identity so a
receiver can distinguish nodes that proposed the same network ID. A node may
eventually resolve a collision by choosing a random replacement ID and sending
a new Presence. The selection, tie-breaking, persistence, and reannouncement
procedure is not defined yet; firmware must not silently merge distinct device
identities while this path is absent. Identity rules for non-STM32 transmitters,
including the Pi, remain to be assigned.

## CAN frame space

ARC-Link uses CAN FD data frames with 29-bit extended arbitration identifiers.
Remote frames and 11-bit standard identifiers are outside this protocol. The
current board implementation uses 500 kbit/s for arbitration and data without
bit-rate switching; this timing still needs hardware validation. The arbitration
identifier is composed as follows:

| Bits | Meaning |
| --- | --- |
| 28–24 | Message class, from `0x00` through `0x1f`. |
| 23–0 | Transmitting node's 24-bit network ID. |

Lower arbitration IDs win bus access. Message class therefore sets bus priority
before the sender ID breaks ties among different nodes in that class. Classes
are assigned to related message types, allowing a receiver to filter by class
in its CAN controller. The class is not a destination address: ARC CAN messages
are broadcast, and any narrower intended audience belongs in the message's
payload and semantics.

| Class | Assignment |
| --- | --- |
| `0x00`–`0x07`, `0x09`–`0x0f` | Unassigned; lower values have higher bus priority. |
| `0x08` | Locomotive throttle control. |
| `0x10` | District control. |
| `0x11` | District status. |
| `0x12` | PSU status. |
| `0x13` | Locomotive throttle status. |
| `0x14` | DCC transmit grants. |
| `0x15` | DCC capability and permission status. |
| `0x16` | Firmware update control and image data. |
| `0x17` | Firmware update acknowledgements. |
| `0x18`–`0x1e` | Unassigned. |
| `0x1f` | Discovery, including Presence. |

For example, node `fa5138` sends Presence under extended CAN ID `0x1ffa5138`.
Only assigned message types may use a class; future assignments must specify
both the class and payload message type.

Two nodes with the same network ID also have the same arbitration identifier
when sending in the same class. If they transmit different frames simultaneously,
CAN arbitration cannot distinguish them and a frame error can result. Presence
makes the collision observable once each announcement is received, but collision
avoidance and recovery still need a defined procedure.

All multibyte integers in payloads are unsigned and big-endian. The source
network ID is obtained from arbitration bits 23–0 and is not repeated in the
payload. All frames start with the following two-byte envelope:

| Offset | Size | Field | Value |
| --- | ---: | --- | --- |
| 0 | 1 | Protocol major version | `0x01` |
| 1 | 1 | Message type | Assigned below |

Receivers discard frames with an unsupported major version. A message format is
identified by its `(class, type)` pair; type values are scoped to their class.
Within discovery class `0x1f`, locomotive throttle control class `0x08`,
district control class `0x10`, district status class `0x11`, PSU status class
`0x12`, and locomotive throttle status class `0x13`, types `0x00`
and `0x02`–`0xff` are unassigned.

## Message `0x01`: Presence

Presence announces the identity behind a network ID. It uses discovery class
`0x1f` and contains exactly 16 data bytes (CAN FD DLC 10):

| Offset | Size | Field | Value |
| --- | ---: | --- | --- |
| 0 | 1 | Protocol major version | `0x01` |
| 1 | 1 | Message type | `0x01` |
| 2 | 1 | Device class | `0x01` for `stm32` |
| 3 | 1 | Flags | `0x00`; all bits reserved |
| 4 | 12 | Device UID | Raw STM32 UID bytes in increasing register-address order |

Presence uses the current network ID in its arbitration identifier; that ID may
eventually differ from the initial hash after collision recovery. A receiver
identifies a physical node by the pair `(device class, device UID)`. If two
Presence messages claim one network ID for different physical identities, the
receiver reports a collision and treats neither claim as an unambiguous control
target.

An STM32 node sends Presence when it joins the bus and periodically while it is
online. The cadence, liveness timeout, and collision-recovery exchange are still
to be specified. Presence announces identity; it does not grant authority, prove
a district is safe, or establish that configuration has been applied.

For the example UID above, the Presence frame is:

```text
extended arbitration ID: 0x1ffa5138
data (16 bytes):          01 01 01 00 00 01 02 03 04 05 06 07 08 09 0a 0b
```

## District control message `0x01`: Configuration

Configuration uses class `0x10` and contains exactly 7 data bytes (CAN FD DLC
7). It replaces the commanded state of one output. Districts boot
disabled, and this command is the only defined CAN path to select an active
mode. The target board ID is in the payload because the arbitration ID identifies
the sender. An unmatched target is ignored.

| Offset | Size | Field | Value |
| --- | ---: | --- | --- |
| 0 | 1 | Protocol major version | `0x01` |
| 1 | 1 | Message type | `0x01` |
| 2 | 3 | Target board network ID | Big-endian 24-bit ID |
| 5 | 1 | District index | `0`–`3` on DST-01x4 |
| 6 | 1 | Commanded state | `0` disabled, `1` active on backbone synchronized DCC, `2` programming |

The receiver rejects the entire frame if its length, envelope, commanded state,
or district index is invalid. Recovery timing is local firmware policy; this
message does not configure it. Repeating the same command
does not restart recovery or clear short backoff. A changed configuration gates
the output off before using a different source or range. A disabled command
clears a latched hardware I/O fault; enabling afterward starts recovery again.

Selecting an active mode does not by itself energize the rails. The selected DCC
source must also be ready, and the district's local protection controls startup
probes and short recovery. Configurations are volatile and must be sent again
after a node restarts. Sender authorization, command acknowledgements, and
collision-safe targeting are still to be defined; a
Presence announcement alone does not make a target unambiguous after an ID
collision.

## District status message `0x01`: Status

Each DST-01x4 output publishes a status in class `0x11` roughly once per second
and whenever its selected mode, actual controller state, or protection-trip flag
changes. State-change reports do not postpone the periodic reports.
Its arbitration ID contains the reporting board's network ID. A status reports
the actual controller state, the selected operating mode, and current measured
over the preceding window. It is a periodic observation rather than a CAN
acknowledgement for a particular command.

| Offset | Size | Field | Value |
| --- | ---: | --- | --- |
| 0 | 1 | Protocol major version | `0x01` |
| 1 | 1 | Message type | `0x01` |
| 2 | 1 | District index | `0`–`3` |
| 3 | 1 | Selected mode | `0` disabled, `1` active, `2` programming |
| 4 | 1 | Actual state | `0` disabled, `1` waiting for source, `2` probing, `3` cooling down, `4` running, `5` hardware fault |
| 5 | 1 | Flags | Bit 0: protection trip detected during current recovery; bit 1: current measurement valid; other bits zero |
| 6 | 2 | Average current | Milliamps, unsigned big-endian, capped at 65,535 |
| 8 | 2 | Peak current | Milliamps, unsigned big-endian, capped at 65,535 |
| 10 | 4 | Measurement window | Elapsed milliseconds since this district's previous status, unsigned big-endian, nonzero |
| 14 | 2 | Reserved | Zero |

The payload is exactly 16 bytes (CAN FD DLC 10). Average current is time
weighted across the stated window, including time when the output is off. Peak
is the highest sampled current in that window. A protection trip remains flagged
through recovery until continuous drive resumes or the district is disabled.
The flag means overcurrent or a driver fault was observed; it does not identify
the precise electrical cause. If current
measurement is unavailable, the validity flag is clear and both current fields
are zero. Status reports the local controller's observation and may lag a recent
command by up to the next controller tick and bus delivery time. A state-change
report can have a shorter current-measurement window than a periodic report.

## PSU status message `0x01`: Status

PSU-01 publishes status in class `0x12` approximately once per second while
the link is online. It also publishes when its state changes to online. Its
arbitration ID contains the PSU's network ID. The payload is exactly 12 bytes
(CAN FD DLC 9):

| Offset | Size | Field | Value |
| --- | ---: | --- | --- |
| 0 | 1 | Protocol major version | `0x01` |
| 1 | 1 | Message type | `0x01` |
| 2 | 1 | Actual state | `0` off, `1` starting, `2` online, `3` fault latched |
| 3 | 1 | Flags | Bit 0: DCC line driver enabled; bit 1: monitor reading valid; other bits zero |
| 4 | 2 | Link voltage | Millivolts, unsigned big-endian |
| 6 | 2 | Link current | Milliamps, unsigned big-endian |
| 8 | 4 | Uptime | Milliseconds since PSU boot, unsigned big-endian, saturating |

If the monitor reading is invalid, both measurement fields are zero. A link
fault can remove power from the receivers before a fault report can be
delivered; the status is an observation, not a guarantee of fault delivery.

## Locomotive throttle control message `0x01`: Set

Set uses class `0x08` and contains exactly 20 data bytes (CAN FD DLC 11).
It replaces one DCC-source throttle-table entry with a complete state. The target source
network ID is in the payload. The sender ID is in the arbitration identifier.

| Offset | Size | Field | Value |
| --- | ---: | --- | --- |
| 0 | 1 | Protocol major version | `0x01` |
| 1 | 1 | Message type | `0x01` |
| 2 | 3 | Target DCC source network ID | Big-endian 24-bit ID |
| 5 | 4 | Command session | Big-endian sender session identifier |
| 9 | 4 | Sequence | Big-endian per-locomotive sequence within the session |
| 13 | 1 | Address kind | `0` short, `1` long |
| 14 | 2 | DCC address | Unsigned big-endian; address validity depends on kind |
| 16 | 1 | Direction | `0` reverse, `1` forward |
| 17 | 1 | Speed step | `0` stop, `1`–`126` motion |
| 18 | 1 | Stop mode | `0` normal, `1` emergency; emergency requires speed `0` |
| 19 | 1 | Reserved | Zero |

The source rejects malformed values, an unmatched target, and a sequence older
than the last accepted sequence for that locomotive within the same command
session. An exact repeat is idempotent and causes another status report. A new
session starts a new sequence space for that locomotive. The session currently
provides correlation and ordering only; it is not an authority grant. A status
report, not CAN transmission, confirms application. DCC transmission requires the separate boot-lifetime grant below.
Sender authentication remains future protocol work.

## Locomotive throttle status message `0x01`: Status

Status uses class `0x13` and contains exactly 20 data bytes (CAN FD DLC 11).
The arbitration identifier identifies the reporting DCC source. It reports a table
entry when that entry changes and periodically while it remains active.

| Offset | Size | Field | Value |
| --- | ---: | --- | --- |
| 0 | 1 | Protocol major version | `0x01` |
| 1 | 1 | Message type | `0x01` |
| 2 | 4 | Command session | Session of last accepted Set |
| 6 | 4 | Sequence | Sequence of last accepted Set |
| 10 | 1 | Address kind | `0` short, `1` long |
| 11 | 2 | DCC address | Unsigned big-endian |
| 13 | 1 | Direction | `0` reverse, `1` forward |
| 14 | 1 | Speed step | `0`–`126` |
| 15 | 1 | Stop mode | `0` normal, `1` emergency |
| 16 | 1 | State | `0` held from DCC transmission, `1` eligible for DCC transmission |
| 17 | 3 | Reserved | Zero |

This reports the source's effective DCC table state. It does not measure decoder
reception or locomotive motion. A receiver must treat status as stale after its
reporting timeout; old status must never restore a throttle request.

## DCC control message `0x01`: Grant

PSU-01 and DST-01 rev1 obey the same transmit permission. Both boot without
permission and keep their DCC line drivers disabled, including idle packets,
until a targeted grant arrives. The grant latches in RAM until the source
restarts. There is no revoke, lease, renewal, handover, or automatic failover.
Repeated grants are idempotent. CAN or layoutd disappearance does not clear it.
Local power qualification still gates actual transmission and does not clear
the permission. District configuration remains independent.

Grant uses class `0x14`, with the sender's network ID in the arbitration ID,
and exactly five data bytes (CAN FD DLC 5):

| Offset | Size | Field | Value |
| --- | ---: | --- | --- |
| 0 | 1 | Protocol major version | `0x01` |
| 1 | 1 | Message type | `0x01` |
| 2 | 3 | Target source network ID | Big-endian 24-bit ID |

Only a capable node matching the target accepts the grant. DST rev2 ignores it.
The current virtual-CAN layoutd uses sender ID `000001`, matching host test
commands; this is a configured lab identity, not a hardware identity derivation.
There is no sender authentication in this protocol version.

## DCC status message `0x01`: Capability and permission

Every implemented board publishes class `0x15` at startup, on changes, and
approximately once per second while CAN is available. The arbitration ID
identifies the reporting node. Exactly four data bytes (CAN FD DLC 4):

| Offset | Size | Field | Value |
| --- | ---: | --- | --- |
| 0 | 1 | Protocol major version | `0x01` |
| 1 | 1 | Message type | `0x01` |
| 2 | 1 | Source kind | `0` no transmitter, `1` PSU, `2` district transmitter |
| 3 | 1 | Flags | Bit 0: permission granted; bit 1: actually transmitting; other bits zero |

A node without a transmitter reports both flags clear. Transmitting requires
permission. Permission may remain set while the output is inhibited by power
qualification. This reports the local line driver, not receiver readiness or
locomotive reception. PSU still supplies link power and CAN discovery before
permission, so layoutd can discover all nodes before allowing DCC.

Layoutd grants only after the layout is `good`: its graph validates and every
expected hardware identity is present, without unexpected or duplicate nodes.
It also waits for all observed nodes to report their DCC capability. It reuses
an already-permitted source if present, otherwise prefers PSU over DST rev1,
then the lowest network ID. It keeps that selection and retries the same grant
once per second until status confirms permission. These are delivery retries,
not renewals. It never reassigns a missing master. After a source restart,
layoutd can grant that same node again when the layout is good.

Throttle Set/Status target and identify the selected DCC source using the
existing formats. Preparing a throttle table never enables the line driver;
source restart clears both permission and the volatile table.

## Firmware update over CAN FD

Classes `0x16` (sender to board) and `0x17` (board acknowledgement) use the
same extended-ID source rule and envelope as other ARC frames. The sender must
use a configured, unique 24-bit network ID. All messages target one board by
the network ID learned from Presence. Only one transfer may be active per board.

The image is a raw application binary linked for the Embassy active partition
at `0x08004000`; its first eight bytes are the little-endian Cortex-M stack
and reset vectors. The bootloader at `0x08000000` is installed separately.
Image kind is `1` for DST-01x4 rev1, `2` for DST-01x4 rev2, and `3` for PSU-01.
The sender computes CRC-32/ISO-HDLC (the same as Python `zlib.crc32`) over the
exact unpadded image. CRC checks transfer integrity; this protocol has no
sender authentication or image signature in version 1.

### Control type `0x01`: Begin

Exactly 20 bytes (CAN FD DLC 11):

| Offset | Size | Field |
| --- | ---: | --- |
| 0–1 | 2 | Version `1`, type `1` |
| 2–4 | 3 | Target network ID |
| 5 | 1 | Image kind |
| 6–9 | 4 | Nonzero transfer session |
| 10–13 | 4 | Image size in bytes |
| 14–17 | 4 | CRC-32 |
| 18–19 | 2 | Zero |

An accepted Begin erases the staging partition and returns Ready with next
offset zero. Repeating Begin restarts the transfer. The board rejects an image
larger than its active partition (240 KiB on rev1; 54 KiB on rev2 or PSU).

### Control type `0x02`: Chunk

Exactly 64 bytes (CAN FD DLC 15):

| Offset | Size | Field |
| --- | ---: | --- |
| 0–1 | 2 | Version `1`, type `2` |
| 2–4 | 3 | Target network ID |
| 5–8 | 4 | Session |
| 9–12 | 4 | Zero-based image offset, a multiple of 48 |
| 13 | 1 | Valid data length, 1–48 |
| 14–61 | 48 | Data, followed by `0xff` padding |
| 62–63 | 2 | `0xff 0xff` |

Each chunk except the last carries 48 valid bytes. The board writes valid
bytes, padded to its eight-byte flash write unit, then acknowledges the next
expected offset. A duplicate of an already accepted chunk gets the current
offset again. An out-of-order chunk is rejected. The sender waits for each
acknowledgement before sending the next chunk and retries on timeout.

### Control type `0x03`: Finish

Exactly 12 bytes (CAN FD DLC 9): version `1`, type `3`, target ID (3 bytes),
session (4 bytes), and three zero bytes. Once the full image is present, the
board reads staging flash back, checks CRC-32, checks that stack and reset
vectors address its RAM and active image, marks the Embassy update pending,
acknowledges Rebooting, and resets. Embassy swaps the image at boot. The new
application confirms its trial boot after initialization; Embassy can restore
the previous image if that confirmation never happens.

### Status type `0x01`: Acknowledgement

Exactly 12 bytes from class `0x17` (CAN FD DLC 9): version `1`, type `1`,
session (4 bytes), next expected offset (4 bytes), phase (1 byte), error
(1 byte). Phase is `1` Ready, `2` Progress, `3` Rebooting, or `4` Rejected.
Error zero means success; rejection errors are `1` wrong kind/size, `2` flash,
`3` session, `4` offset/length, `5` CRC, and `6` vector address. The board's
network ID in the arbitration identifier identifies the responder.

During staging, DST disables its districts and rev1 DCC transmission. PSU
keeps ARC-Link and CAN powered but inhibits its DCC transmitter. An interrupted
transfer leaves the current application intact; send Begin again to retry.

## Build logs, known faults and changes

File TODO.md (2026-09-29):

# TODO

- 2026-09-15 stackup-footprints: redraw RJ11_Stewart_SS-90000-006_Horizontal's Fab/courtyard from CT900006 — panel stop is 15.80 wide (land has Amphenol's 13.62/14.42) and the face is 10.34 in front of the pegs (land stops at ~7.9); trk-hub-01 rev 1 placed its three jacks on a 15.2–15.4 pitch, so the middle jack's panel stop is ground down to seat. Re-check jack pitch on trk-led/trn/srv/nfc when their layouts are next touched.

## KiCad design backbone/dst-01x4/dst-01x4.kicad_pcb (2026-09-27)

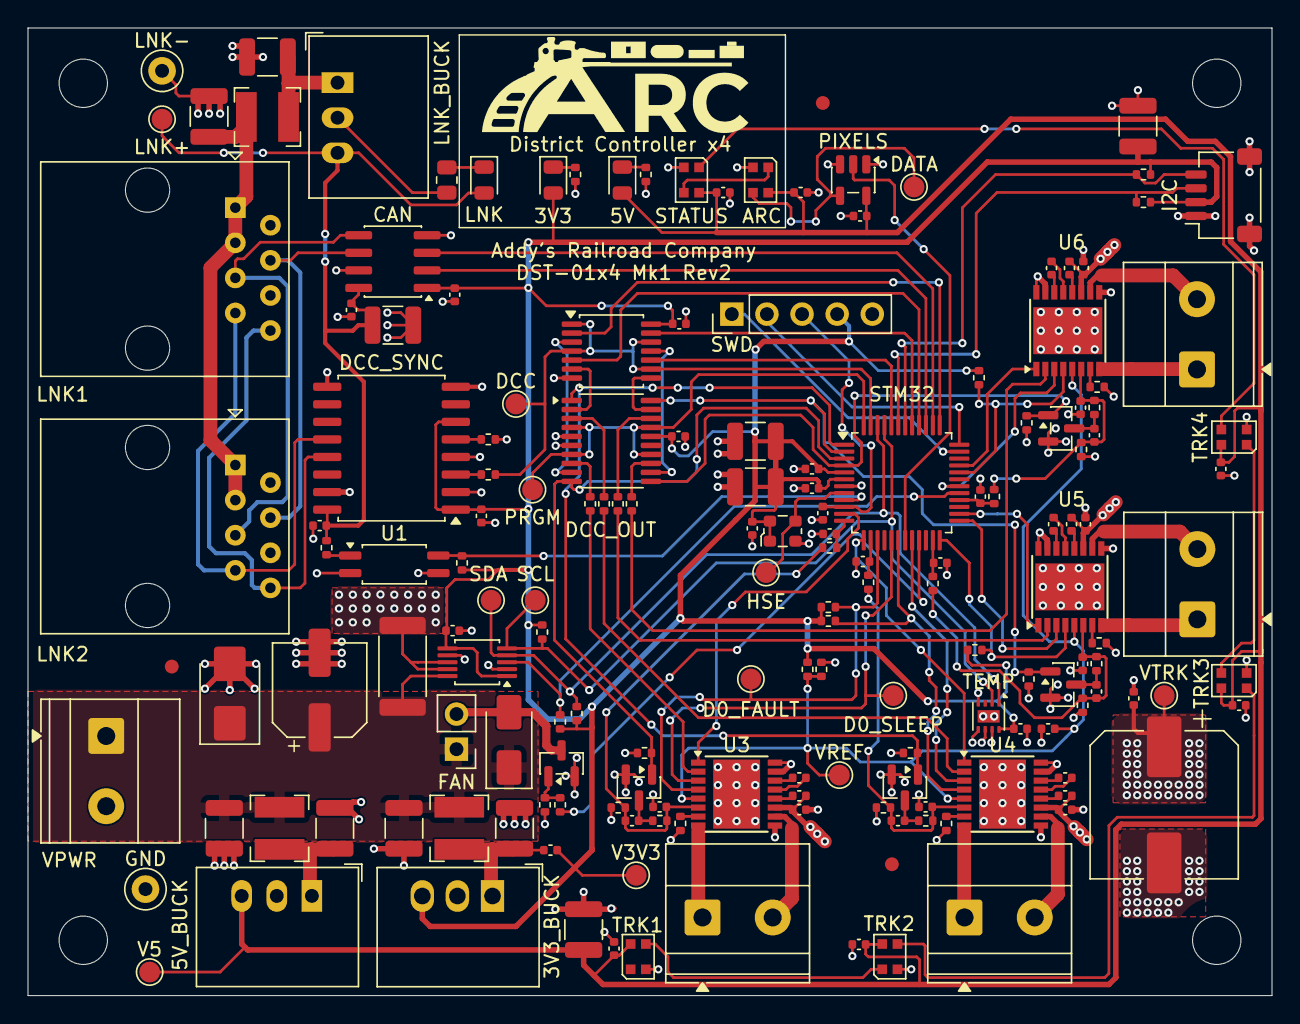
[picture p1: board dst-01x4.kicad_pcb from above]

Board: 4 copper layers, 90.0 x 70.0 mm, 172 parts (0 on the bottom side), 114 nets.

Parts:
3V3, 5V: green; LED_0805_2012Metric
3V3_BUCK: R-78K3.3-0.5; Converter_DCDC_RECOM_R-78K-0.5_THT
5V_BUCK: R-78E5.0-0.5; Converter_DCDC_RECOM_R-78E-0.5_THT
ARC: WS2812B-2020; LED_WS2812B-2020_PLCC4_2.0x2.0mm
C1: 47µF; CP_Elec_6.3x7.7
C2, C3, C8, C17, C19, C32: 10µF; C_1210_3225Metric
C4, C56, C57, C58, C59: 1nF; C_0402_1005Metric
C5, C7, C10, C11, C12, C13, C14, C15, C16, C18, C21, C22, C24, C25, C26, C28, C30, C31, C33, C34, C35, C36, C38, C40, C41, C43, C45, C46, C48, C50, C51, C53, C55: 100nF; C_0402_1005Metric
C6: 220µF; CP_Elec_10x16.5
C9, C20, C23, C27: 4.7µF; C_1210_3225Metric
C29: 1µF; C_1210_3225Metric
C37, C42, C47, C52: 22nF; C_0402_1005Metric
C39, C44, C49, C54: 10nF; C_0402_1005Metric
CAN: ISO1044BD; SOIC-8_3.9x4.9mm_P1.27mm
D0_FAULT, D0_SLEEP: TestPoint; TestPoint_Pad_D1.5mm
D1: SMBJ18A; D_SMB
D2, D3, D4, D5: WS2812B-2020; LED_WS2812B-2020_PLCC4_2.0x2.0mm
D6: SS14; D_SMA
DATA: TestPoint; TestPoint_Pad_D1.5mm
DCC: TestPoint; TestPoint_Pad_D1.5mm
DCC_OUT: ADG734; TSSOP-20_4.4x6.5mm_P0.65mm
DCC_SYNC: ISO1430DW; SOIC-16W_7.5x10.3mm_P1.27mm
FAN: Conn_01x02; PinHeader_1x02_P2.54mm_Vertical
FID1, FID2, FID3: Fiducial; Fiducial_1mm_Mask2mm
GND: TestPoint; TestPoint_Loop_D2.50mm_Drill1.0mm
H1, H2, H3, H4: MountingHole; MountingHole_3.5mm
HSE: TestPoint; TestPoint_Pad_D1.5mm
I2C: Conn_01x04_MountingPin; JST_SH_SM04B-SRSS-TB_1x04-1MP_P1.00mm_Horizontal
L1: 100µH; L_Bourns-SRN4018
L2, L3: 15µH; L_Bourns-SRN4018
LNK: green; LED_0805_2012Metric
LNK1, LNK2: RJ45; RJ45_Amphenol_54602-x08_Horizontal
LNK+: TestPoint; TestPoint_Pad_D1.5mm
LNK-: TestPoint; TestPoint_Loop_D2.50mm_Drill1.0mm
LNK_BUCK: R-78E5.0-0.5; Converter_DCDC_RECOM_R-78E-0.5_THT
MON: INA226; TSSOP-10_3x3mm_P0.5mm
PIXELS: 74AHCT1G125; SOT-23-5
PRGM: TestPoint; TestPoint_Pad_D1.5mm
Q1: DMN3404L; SOT-23
Q2, Q3, Q4, Q5: BSS138; SOT-23
R1: 5mΩ; R_2512_6332Metric
R2, R42, R43, R44, R45: 1kΩ; R_0402_1005Metric
R3: 100Ω; R_0402_1005Metric
R4, R6, R18, R23, R28, R33: 10kΩ; R_0402_1005Metric
R5: 300Ω; R_0805_2012Metric
R7: 2kΩ; R_0402_1005Metric
R8, R20, R25, R30, R35: 100kΩ; R_0402_1005Metric
R9: 680Ω; R_0402_1005Metric
R10: 1.5kΩ; R_0402_1005Metric
R11, R12, R13, R14: 4.7kΩ; R_0402_1005Metric
R15: 33Ω; R_0402_1005Metric
R16: 9.76kΩ; R_0402_1005Metric
R17: 30kΩ; R_0402_1005Metric
R19, R24, R29, R34: 20kΩ; R_0402_1005Metric
R21, R26, R31, R36: 22.1kΩ; R_0402_1005Metric
R22, R27, R32, R37: 2.49kΩ; R_0402_1005Metric
R38, R39, R40, R41: 22Ω; R_0402_1005Metric
SCL: TestPoint; TestPoint_Pad_D1.5mm
SDA: TestPoint; TestPoint_Pad_D1.5mm
STATUS: WS2812B-2020; LED_WS2812B-2020_PLCC4_2.0x2.0mm
STM32: STM32C092CBTx; LQFP-48_7x7mm_P0.5mm
SWD: Conn_01x05; PinHeader_1x05_P2.54mm_Vertical
TEMP: TMP1075DSG; WSON-8-1EP_2x2mm_P0.5mm_EP0.9x1.6mm
TRK1, TRK2, TRK3, TRK4: Conn_01x02; TerminalBlock_Phoenix_MKDS-1,5-2-5.08_1x02_P5.08mm_Horizont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
U1: FODM217A; SOP-4_4.4x2.6mm_P1.27mm
U2: 74HC86; TSSOP-14_4.4x5mm_P0.65mm
U3, U4, U5, U6: DRV8874PWPR; HTSSOP-16-1EP_4.4x5mm_P0.65mm_EP3.4x5mm
V3V3, V5: TestPoint; TestPoint_Pad_D1.5mm
VPWR: Conn_01x02; TerminalBlock_Phoenix_MKDS-1,5-2-5.08_1x02_P5.08mm_Horizont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
VREF: TestPoint; TestPoint_Pad_D1.5mm
VTRK: TestPoint; TestPoint_Pad_D1.5mm
Y1: 40MHz; Oscillator_SMD_ECS_2520MV-xxx-xx-4Pin_2.5x2.0mm

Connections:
DCC: DCC.1, R15.2, STM32.47, U2.1, U2.4, U2.9, U2.12
DCC_PROG: DCC_OUT.4, DCC_OUT.7, DCC_OUT.14, DCC_OUT.17, PRGM.1, STM32.48
DCC_RO: DCC_SYNC.3, R15.1
unnamed: 3V3.1, R9.1
unnamed: 3V3_BUCK.1, C3.1, C4.1, L1.2
unnamed: 5V.1, R10.1
unnamed: 5V_BUCK.1, C9.1, L2.2
unnamed: ARC.1, STATUS.3
unnamed: D2.1, D3.3
unnamed: D3.1, D4.3
unnamed: D4.1, D5.3
unnamed: LNK.1, R5.1
unnamed: C20.1, L3.2, LNK_BUCK.1
unnamed: Q1.1, R3.2, R4.1
unnamed: C40.2, Q2.3, R22.2
unnamed: C45.2, Q3.3, R27.2
unnamed: C50.2, Q4.3, R32.2
unnamed: C55.2, Q5.3, R37.2
unnamed: R7.2, U1.1
unnamed: C37.1, U3.13
unnamed: C37.2, U3.14
unnamed: R19.1, U3.7
unnamed: C38.2, U3.12
unnamed: C42.1, U4.13
unnamed: C42.2, U4.14
unnamed: R24.1, U4.7
unnamed: C43.2, U4.12
unnamed: C47.1, U5.13
unnamed: C47.2, U5.14
unnamed: R29.1, U5.7
unnamed: C48.2, U5.12
unnamed: C52.1, U6.13
unnamed: C52.2, U6.14
unnamed: R34.1, U6.7
unnamed: C53.2, U6.12
PHASE0: STM32.37, U2.2
PHASE1: STM32.40, U2.5
PHASE2: STM32.44, U2.10
PHASE3: STM32.41, U2.13
SIGNAL0: DCC_OUT.8, R38.1
SIGNAL1: DCC_OUT.3, R39.1
SIGNAL2: DCC_OUT.18, R40.1
SIGNAL3: DCC_OUT.13, R41.1
STREAM0: DCC_OUT.9, U2.3
STREAM1: DCC_OUT.2, U2.6
STREAM2: DCC_OUT.19, U2.8
STREAM3: DCC_OUT.12, U2.11
VREF: C35.1, R16.2, R17.1, U3.5, U4.5, U5.5, U6.5, VREF.1
adc0/adc: C56.1, R42.1, STM32.12
adc1/adc: C57.1, R43.1, STM32.14
adc2/adc: C58.1, R44.1, STM32.23
adc3/adc: C59.1, R45.1, STM32.28
d0/A: TRK1.1, U3.8
d0/B: TRK1.2, U3.10
d0/DCC: R38.2, U3.2
d0/ISENSE: C39.1, C40.1, R21.1, R22.1, R42.2, U3.6
d0/PWM: STM32.11, U3.1
d0/nFAULT: D0_FAULT.1, R18.1, STM32.15, U3.4
d0/nSLEEP: D0_SLEEP.1, STM32.17, U3.3
d1/A: TRK2.1, U4.8
d1/B: TRK2.2, U4.10
d1/DCC: R39.2, U4.2
d1/ISENSE: C44.1, C45.1, R26.1, R27.1, R43.2, U4.6
d1/PWM: STM32.13, U4.1
d1/nFAULT: R23.1, STM32.18, U4.4
d1/nSLEEP: STM32.20, U4.3
d2/A: TRK3.1, U5.8
d2/B: TRK3.2, U5.10
d2/DCC: R40.2, U5.2
d2/ISENSE: C49.1, C50.1, R31.1, R32.1, R44.2, U5.6
d2/PWM: STM32.26, U5.1
d2/nFAULT: R28.1, STM32.24, U5.4
d2/nSLEEP: STM32.25, U5.3
d3/A: TRK4.1, U6.8
d3/B: TRK4.2, U6.10
d3/DCC: R41.2, U6.2
d3/ISENSE: C54.1, C55.1, R36.1, R37.1, R45.2, U6.6
d3/PWM: STM32.33, U6.1
d3/nFAULT: R33.1, STM32.32, U6.4
d3/nSLEEP: STM32.30, U6.3
dc/GND: 3V3_BUCK.2, 5V_BUCK.2, ARC.2, C1.2, C2.2, C3.2, C5.2, C6.2, C7.2, C8.2, C9.2, C10.2, C11.2, C12.2, C13.2, C14.2, C15.2, C16.2, C17.2, C18.2, C21.2, C24.2, C26.2, C27.2, C28.2, C29.2, C30.2, C31.2, C32.2, C33.2, C34.2, C35.2, C36.2, C39.2, C41.2, C44.2, C46.2, C49.2, C51.2, C54.2, C56.2, C57.2, C58.2, C59.2, CAN.4, D1.2, D2.2, D3.2, D4.2, D5.2, DCC_OUT.5, DCC_OUT.6, DCC_SYNC.2, DCC_SYNC.4, DCC_SYNC.8, GND.1, I2C.1, I2C.MP, MON.2, MON.7, PIXELS.1, PIXELS.3, Q1.2, Q2.2, Q3.2, Q4.2, Q5.2, R4.2, R6.2, R9.2, R10.2, R17.2, R19.2, R20.2, R21.2, R24.2, R25.2, R26.2, R29.2, R30.2, R31.2, R34.2, R35.2, R36.2, STATUS.2, STM32.7, SWD.5, TEMP.4, TEMP.5, TEMP.6, TEMP.7, TEMP.9, U1.3, U2.7, U3.9, U3.15, U3.16, U3.17, U4.9, U4.15, U4.16, U4.17, U5.9, U5.15, U5.16, U5.17, U6.9, U6.15, U6.16, U6.17, VPWR.2, Y1.2
dc/VPWR: C1.1, C2.1, C8.1, D1.1, D6.1, FAN.1, L1.1, L2.1, MON.10, R1.1, VPWR.1
exp-pulls/i2c.scl: I2C.4, R14.1, STM32.42
exp-pulls/i2c.sda: I2C.3, R13.1, STM32.43
fan/en: R3.1, STM32.21
hse: HSE.1, STM32.8, Y1.3
indicator/DIN: ARC.3, DATA.1, PIXELS.4
indicator/board/out: D2.3, STATUS.1
indicator/data: PIXELS.2, STM32.19
indicator/v5.rail: 5V.2, 5V_BUCK.3, ARC.4, C10.1, C11.1, C12.1, C13.1, C14.1, C15.1, C16.1, C17.1, D2.4, D3.4, D4.4, D5.4, PIXELS.5, STATUS.4, V5.1
link/V5_LINK: C22.1, C23.1, C25.1, CAN.8, DCC_SYNC.16, LNK.2, LNK+.1, LNK_BUCK.3, R7.1
link/VLINK: C19.1, L3.1, LNK1.1, LNK1.3, LNK2.1, LNK2.3
link/VLINK_GND: C19.2, C20.2, C22.2, C23.2, C25.2, CAN.7, DCC_SYNC.9, DCC_SYNC.15, LNK1.2, LNK1.6, LNK2.2, LNK2.6, LNK-.1, LNK_BUCK.2, R5.2, U1.2
link/dcc-de: DCC_SYNC.5, R6.1
link/fdcan.rx: CAN.3, STM32.38
link/fdcan.tx: CAN.2, STM32.39
link/good: R8.1, STM32.9, U1.4
link/jacks/CANH: CAN.6, LNK1.4, LNK2.4
link/jacks/CANL: CAN.5, LNK1.5, LNK2.5
link/jacks/DCC_A: DCC_SYNC.12, LNK1.7, LNK2.7
link/jacks/DCC_B: DCC_SYNC.13, LNK1.8, LNK2.8
nALERT: MON.3, R2.1, STM32.29
nPROG0: DCC_OUT.10, Q2.1, R20.1, STM32.3
nPROG1: DCC_OUT.1, Q3.1, R25.1, STM32.1
nPROG2: DCC_OUT.20, Q4.1, R30.1, STM32.2
nPROG3: DCC_OUT.11, Q5.1, R35.1, STM32.4
nrst: C28.1, STM32.10, SWD.3
swd/swd.swclk: STM32.36, SWD.2
swd/swd.swdio: STM32.35, SWD.1
thermal/fan/-: D6.2, FAN.2, Q1.3
track/VTRK: C6.1, C7.1, C36.1, C38.1, C41.1, C43.1, C46.1, C48.1, C51.1, C53.1, MON.8, MON.9, R1.2, U3.11, U4.11, U5.11, U6.11, VTRK.1
track/i2c.scl: MON.5, R12.1, SCL.1, STM32.45, TEMP.2
track/i2c.sda: MON.4, R11.1, SDA.1, STM32.46, TEMP.1
track/logic.rail: 3V3.2, 3V3_BUCK.3, C4.2, C5.1, C18.1, C21.1, C24.1, C26.1, C27.1, C29.1, C30.1, C31.1, C32.1, C33.1, C34.1, CAN.1, DCC_OUT.16, DCC_SYNC.1, DCC_SYNC.6, I2C.2, MON.1, MON.6, R2.2, R8.2, R11.2, R12.2, R13.2, R14.2, R16.1, R18.2, R23.2, R28.2, R33.2, STM32.5, STM32.6, SWD.4, TEMP.8, U2.14, V3V3.1, Y1.1, Y1.4

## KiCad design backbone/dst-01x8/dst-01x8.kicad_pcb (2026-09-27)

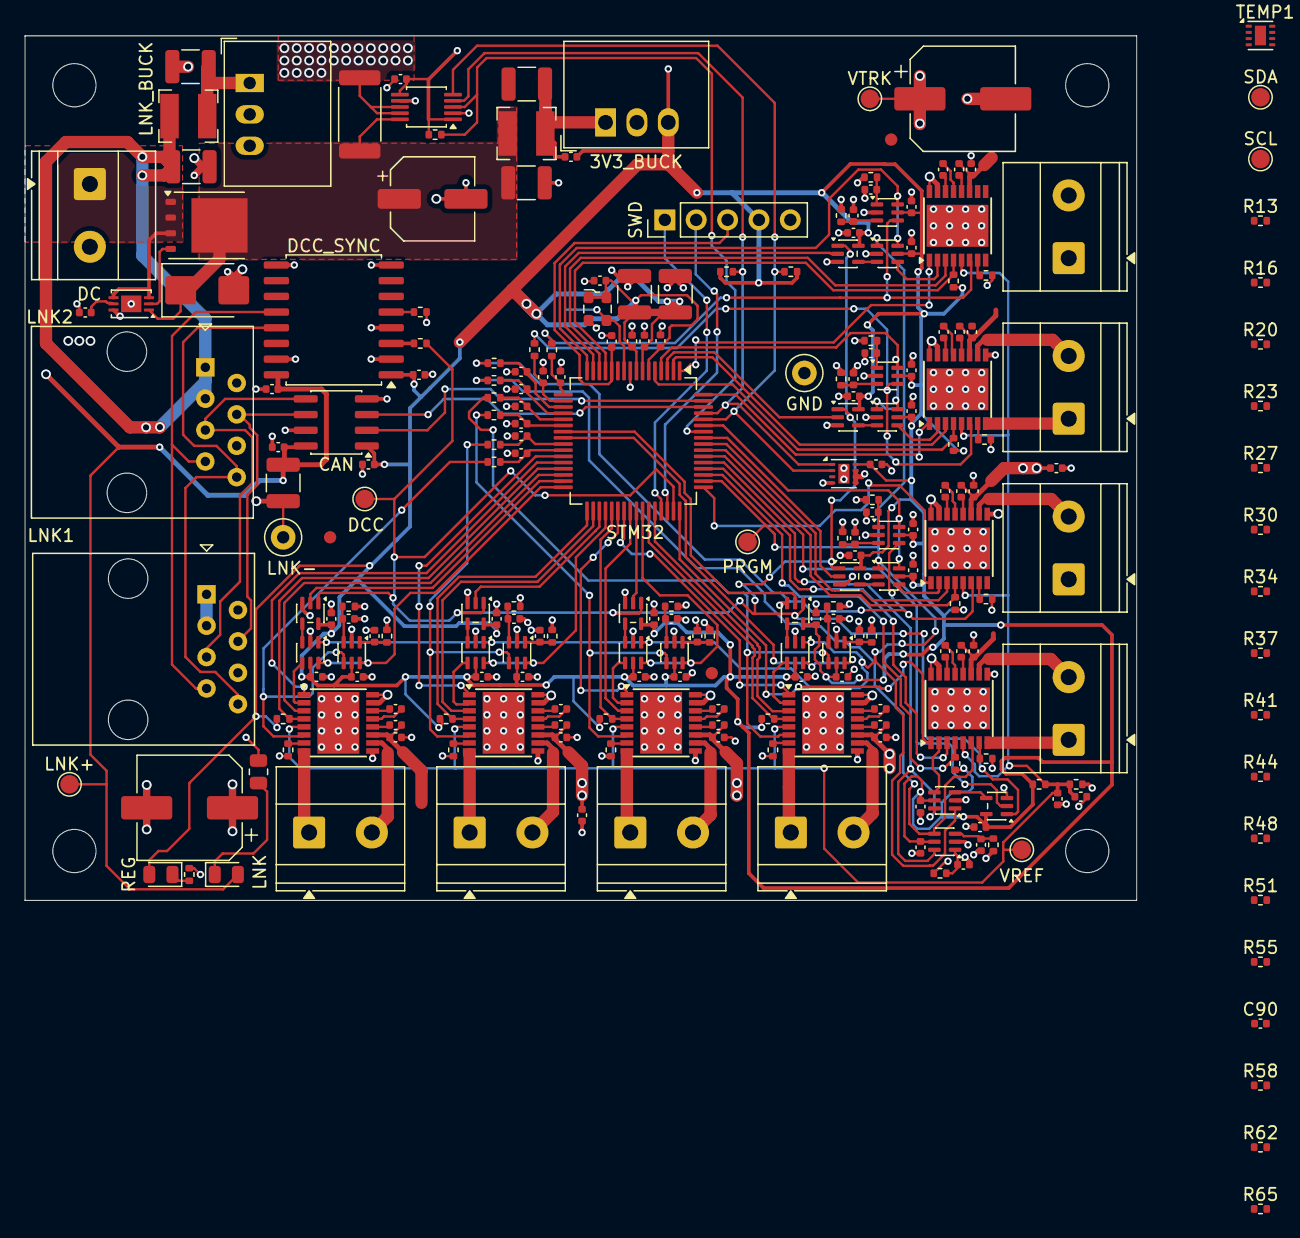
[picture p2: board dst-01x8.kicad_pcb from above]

Board: 4 copper layers, 90.0 x 70.0 mm, 243 parts (1 on the bottom side), 176 nets.

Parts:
3V3_BUCK: R-78K3.3-0.5; Converter_DCDC_RECOM_R-78K-0.5_THT
C1, C34, C43, C52, C61, C70, C79, C88, C97: 10nF; C_0402_1005Metric
C2: 47µF; CP_Elec_6.3x7.7
C3, C4, C15: 10µF; C_1210_3225Metric
C5, C37, C46, C55, C64, C73, C82, C91, C100: 1nF; C_0402_1005Metric
C6, C9, C10, C11, C12, C13, C14, C17, C18, C20, C21, C22, C24, C25, C27, C28, C29, C31, C32, C33, C35, C36, C38, C40, C41, C42, C44, C45, C47, C49, C50, C51, C53, C54, C56, C58, C59, C60, C62, C63, C65, C67, C68, C69, C71, C72, C74, C76, C77, C78, C80, C81, C83, C85, C86, C87, C89, C90, C92, C94, C95, C96, C98, C99: 100nF; C_0402_1005Metric
C7, C8: 100µF; CP_Elec_8x11.9
C16, C19, C23: 4.7µF; C_1210_3225Metric
C26: 1µF; C_1210_3225Metric
C30, C39, C48, C57, C66, C75, C84, C93: 22nF; C_0402_1005Metric
CAN: ISO1044BD; SOIC-8_3.9x4.9mm_P1.27mm
D1: SMBJ18A; D_SMB
DC: Conn_01x02; TerminalBlock_Phoenix_MKDS-1,5-2-5.08_1x02_P5.08mm_Horizont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
DCC: TestPoint; TestPoint_Pad_D1.5mm
DCC_SYNC: ISO1430DW; SOIC-16W_7.5x10.3mm_P1.27mm
FID1, FID2, FID3: Fiducial; Fiducial_1mm_Mask2mm
GND: TestPoint; TestPoint_Loop_D2.50mm_Drill1.0mm
H1, H2, H3, H4: MountingHole; MountingHole_3.5mm
HSE: TestPoint; TestPoint_Pad_D1.5mm
L1: 100µH; L_Bourns-SRN4018
L2: 15µH; L_Bourns-SRN4018
LNK: green; LED_0805_2012Metric
LNK1, LNK2: RJ45; RJ45_Amphenol_54602-x08_Horizontal
LNK+: TestPoint; TestPoint_Pad_D1.5mm
LNK-: TestPoint; TestPoint_Loop_D2.50mm_Drill1.0mm
LNK_BUCK: R-78E5.0-0.5; Converter_DCDC_RECOM_R-78E-0.5_THT
MON: INA226; TSSOP-10_3x3mm_P0.5mm
PRGM: TestPoint; TestPoint_Pad_D1.5mm
Q1: BSC030N08NS5; TDSON-8-1
R1: 3mΩ; R_2512_6332Metric
R2, R17, R24, R31, R38, R45, R52, R59, R66: 1kΩ; R_0402_1005Metric
R3: 9.76kΩ; R_0402_1005Metric
R4: 30kΩ; R_0402_1005Metric
R5: 300Ω; R_0805_2012Metric
R6, R11, R18, R25, R32, R39, R46, R53, R60: 10kΩ; R_0402_1005Metric
R7: 680Ω; R_0402_1005Metric
R8, R9: 4.7kΩ; R_0402_1005Metric
R10: 33Ω; R_0402_1005Metric
R12, R19, R26, R33, R40, R47, R54, R61: 20kΩ; R_0402_1005Metric
R13, R20, R27, R34, R41, R48, R55, R62: 100kΩ; R_0402_1005Metric
R14, R21, R28, R35, R42, R49, R56, R63: 2.21kΩ; R_0402_1005Metric
R15, R22, R29, R36, R43, R50, R57, R64: 22.1kΩ; R_0402_1005Metric
R16, R23, R30, R37, R44, R51, R58, R65: 22Ω; R_0402_1005Metric
REG: green; LED_0805_2012Metric
SCL: TestPoint; TestPoint_Pad_D1.5mm
SDA: TestPoint; TestPoint_Pad_D1.5mm
STM32: STM32G0B1RETx; LQFP-64_10x10mm_P0.5mm
SWD: Conn_01x05; PinHeader_1x05_P2.54mm_Vertical
TEMP0, TEMP1: TMP1075DSG; WSON-8-1EP_2x2mm_P0.5mm_EP0.9x1.6mm
TRK1, TRK2, TRK3, TRK4, TRK5, TRK6, TRK7, TRK8: Conn_01x02; TerminalBlock_Phoenix_MKDS-1,5-2-5.08_1x02_P5.08mm_Horizont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
U1: LTC4359-DCB; DFN-6-1EP_3x2mm_P0.5mm_EP1.65x1.35mm
U2, U6, U10, U14, U18, U22, U26, U30: DRV8874PWPR; HTSSOP-16-1EP_4.4x5mm_P0.65mm_EP3.4x5mm
U3, U5, U7, U9, U11, U13, U15, U17, U19, U21, U23, U25, U27, U29, U31, U33: 74LVC1G3157; SOT-363_SC-70-6
U4, U8, U12, U16, U20, U24, U28, U32: 74LVC1G86; SOT-353_SC-70-5
VREF: TestPoint; TestPoint_Pad_D1.5mm
VTRK: TestPoint; TestPoint_Pad_D1.5mm
Y1: 40MHz; Oscillator_SMD_ECS_2520MV-xxx-xx-4Pin_2.5x2.0mm

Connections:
DCC: DCC.1, R10.2, STM32.47, U4.1, U8.1, U12.1, U16.1, U20.1, U24.1, U28.1, U32.1
DCC_PROG: PRGM.1, STM32.50, U5.1, U9.1, U13.1, U17.1, U21.1, U25.1, U29.1, U33.1
DCC_RO: DCC_SYNC.3, R10.1
unnamed: 3V3_BUCK.1, C4.1, C5.1, L1.2
unnamed: LNK.1, R5.1
unnamed: C16.1, L2.2, LNK_BUCK.1
unnamed: R7.1, REG.1
unnamed: Q1.4, U1.2
unnamed: C1.1, U1.5
unnamed: C30.1, U2.13
unnamed: C30.2, U2.14
unnamed: R12.1, U2.7
unnamed: C31.2, U2.12
unnamed: C33.1, R14.1, U3.3
unnamed: C34.1, R15.1, U3.1
unnamed: C39.1, U6.13
unnamed: C39.2, U6.14
unnamed: R19.1, U6.7
unnamed: C40.2, U6.12
unnamed: C42.1, R21.1, U7.3
unnamed: C43.1, R22.1, U7.1
unnamed: C48.1, U10.13
unnamed: C48.2, U10.14
unnamed: R26.1, U10.7
unnamed: C49.2, U10.12
unnamed: C51.1, R28.1, U11.3
unnamed: C52.1, R29.1, U11.1
unnamed: C57.1, U14.13
unnamed: C57.2, U14.14
unnamed: R33.1, U14.7
unnamed: C58.2, U14.12
unnamed: C60.1, R35.1, U15.3
unnamed: C61.1, R36.1, U15.1
unnamed: C66.1, U18.13
unnamed: C66.2, U18.14
unnamed: R40.1, U18.7
unnamed: C67.2, U18.12
unnamed: C69.1, R42.1, U19.3
unnamed: C70.1, R43.1, U19.1
unnamed: C75.1, U22.13
unnamed: C75.2, U22.14
unnamed: R47.1, U22.7
unnamed: C76.2, U22.12
unnamed: C78.1, R49.1, U23.3
unnamed: C79.1, R50.1, U23.1
unnamed: C84.1, U26.13
unnamed: C84.2, U26.14
unnamed: R54.1, U26.7
unnamed: C85.2, U26.12
unnamed: C87.1, R56.1, U27.3
unnamed: C88.1, R57.1, U27.1
unnamed: C93.1, U30.13
unnamed: C93.2, U30.14
unnamed: R61.1, U30.7
unnamed: C94.2, U30.12
unnamed: C96.1, R63.1, U31.3
unnamed: C97.1, R64.1, U31.1
PHASE0: STM32.31, U4.2
PHASE1: STM32.35, U8.2
PHASE2: STM32.41, U12.2
PHASE3: STM32.23, U16.2
PHASE4: STM32.54, U20.2
PHASE5: STM32.57, U24.2
PHASE6: STM32.3, U28.2
PHASE7: STM32.15, U32.2
PROG0: STM32.32, U3.6, U5.6
PROG1: STM32.36, U7.6, U9.6
PROG2: STM32.42, U11.6, U13.6
PROG3: STM32.24, U15.6, U17.6
PROG4: STM32.53, U19.6, U21.6
PROG5: STM32.59, U23.6, U25.6
PROG6: STM32.4, U27.6, U29.6
PROG7: STM32.16, U31.6, U33.6
SIGNAL0: R16.1, U5.4
SIGNAL1: R23.1, U9.4
SIGNAL2: R30.1, U13.4
SIGNAL3: R37.1, U17.4
SIGNAL4: R44.1, U21.4
SIGNAL5: R51.1, U25.4
SIGNAL6: R58.1, U29.4
SIGNAL7: R65.1, U33.4
STREAM0: U4.4, U5.3
STREAM1: U8.4, U9.3
STREAM2: U12.4, U13.3
STREAM3: U16.4, U17.3
STREAM4: U20.4, U21.3
STREAM5: U24.4, U25.3
STREAM6: U28.4, U29.3
STREAM7: U32.4, U33.3
adc0/adc: C37.1, R17.1, STM32.26
adc1/adc: C46.1, R24.1, STM32.25
adc2/adc: C55.1, R31.1, STM32.22
adc3/adc: C64.1, R38.1, STM32.21
adc4/adc: C73.1, R45.1, STM32.20
adc5/adc: C82.1, R52.1, STM32.19
adc6/adc: C91.1, R59.1, STM32.18
adc7/adc: C100.1, R66.1, STM32.17
d0/A: TRK1.1, U2.8
d0/B: TRK1.2, U2.10
d0/DCC: R16.2, U2.2
d0/ISENSE: R17.2, U2.6, U3.4
d0/PWM: STM32.28, U2.1
d0/nFAULT: R11.1, STM32.29, U2.4
d0/nSLEEP: R13.1, STM32.30, U2.3
d1/A: TRK2.1, U6.8
d1/B: TRK2.2, U6.10
d1/DCC: R23.2, U6.2
d1/ISENSE: R24.2, U6.6, U7.4
d1/PWM: STM32.27, U6.1
d1/nFAULT: R18.1, STM32.33, U6.4
d1/nSLEEP: R20.1, STM32.34, U6.3
d2/A: TRK3.1, U10.8
d2/B: TRK3.2, U10.10
d2/DCC: R30.2, U10.2
d2/ISENSE: R31.2, U10.6, U11.4
d2/PWM: STM32.38, U10.1
d2/nFAULT: R25.1, STM32.37, U10.4
d2/nSLEEP: R27.1, STM32.40, U10.3
d3/A: TRK4.1, U14.8
d3/B: TRK4.2, U14.10
d3/DCC: R37.2, U14.2
d3/ISENSE: R38.2, U14.6, U15.4
d3/PWM: STM32.39, U14.1
d3/nFAULT: R32.1, STM32.43, U14.4
d3/nSLEEP: R34.1, STM32.44, U14.3
d4/A: TRK5.1, U18.8
d4/B: TRK5.2, U18.10
d4/DCC: R44.2, U18.2
d4/ISENSE: R45.2, U18.6, U19.4
d4/PWM: STM32.48, U18.1
d4/nFAULT: R39.1, STM32.51, U18.4
d4/nSLEEP: R41.1, STM32.52, U18.3
d5/A: TRK6.1, U22.8
d5/B: TRK6.2, U22.10
d5/DCC: R51.2, U22.2
d5/ISENSE: R52.2, U22.6, U23.4
d5/PWM: STM32.49, U22.1
d5/nFAULT: R46.1, STM32.55, U22.4
d5/nSLEEP: R48.1, STM32.56, U22.3
d6/A: TRK7.1, U26.8
d6/B: TRK7.2, U26.10
d6/DCC: R58.2, U26.2
d6/ISENSE: R59.2, U26.6, U27.4
d6/PWM: STM32.64, U26.1
d6/nFAULT: R53.1, STM32.5, U26.4
d6/nSLEEP: R55.1, STM32.2, U26.3
d7/A: TRK8.1, U30.8
d7/B: TRK8.2, U30.10
d7/DCC: R65.2, U30.2
d7/ISENSE: R66.2, U30.6, U31.4
d7/PWM: STM32.1, U30.1
d7/nFAULT: R60.1, STM32.13, U30.4
d7/nSLEEP: R62.1, STM32.14, U30.3
dc/DC_IN: DC.1, Q1.1, Q1.2, Q1.3, U1.3, U1.4
dc/GND: 3V3_BUCK.2, C1.2, C2.2, C3.2, C4.2, C6.2, C7.2, C8.2, C9.2, C10.2, C11.2, C12.2, C13.2, C14.2, C17.2, C20.2, C22.2, C23.2, C24.2, C25.2, C26.2, C27.2, C28.2, C29.2, C32.2, C33.2, C34.2, C35.2, C36.2, C37.2, C38.2, C41.2, C42.2, C43.2, C44.2, C45.2, C46.2, C47.2, C50.2, C51.2, C52.2, C53.2, C54.2, C55.2, C56.2, C59.2, C60.2, C61.2, C62.2, C63.2, C64.2, C65.2, C68.2, C69.2, C70.2, C71.2, C72.2, C73.2, C74.2, C77.2, C78.2, C79.2, C80.2, C81.2, C82.2, C83.2, C86.2, C87.2, C88.2, C89.2, C90.2, C91.2, C92.2, C95.2, C96.2, C97.2, C98.2, C99.2, C100.2, CAN.4, D1.2, DC.2, DCC_SYNC.2, DCC_SYNC.4, DCC_SYNC.8, GND.1, MON.2, MON.7, R4.2, R6.2, R7.2, R12.2, R13.2, R14.2, R15.2, R19.2, R20.2, R21.2, R22.2, R26.2, R27.2, R28.2, R29.2, R33.2, R34.2, R35.2, R36.2, R40.2, R41.2, R42.2, R43.2, R47.2, R48.2, R49.2, R50.2, R54.2, R55.2, R56.2, R57.2, R61.2, R62.2, R63.2, R64.2, STM32.9, SWD.5, TEMP0.4, TEMP0.5, TEMP0.6, TEMP0.7, TEMP0.9, TEMP1.4, TEMP1.5, TEMP1.6, TEMP1.9, U1.6, U1.7, U2.9, U2.15, U2.16, U2.17, U3.2, U4.3, U5.2, U6.9, U6.15, U6.16, U6.17, U7.2, U8.3, U9.2, U10.9, U10.15, U10.16, U10.17, U11.2, U12.3, U13.2, U14.9, U14.15, U14.16, U14.17, U15.2, U16.3, U17.2, U18.9, U18.15, U18.16, U18.17, U19.2, U20.3, U21.2, U22.9, U22.15, U22.16, U22.17, U23.2, U24.3, U25.2, U26.9, U26.15, U26.16, U26.17, U27.2, U28.3, U29.2, U30.9, U30.15, U30.16, U30.17, U31.2, U32.3, U33.2, Y1.2
dc/VPWR: C2.1, C3.1, D1.1, L1.1, MON.10, Q1.5, R1.1, U1.1
hse: HSE.1, STM32.10, Y1.3
link/V5_LINK: C18.1, C19.1, C21.1, CAN.8, DCC_SYNC.16, LNK.2, LNK+.1, LNK_BUCK.3
link/VLINK: C15.1, L2.1, LNK1.1, LNK1.3, LNK2.1, LNK2.3
link/VLINK_GND: C15.2, C16.2, C18.2, C19.2, C21.2, CAN.7, DCC_SYNC.9, DCC_SYNC.15, LNK1.2, LNK1.6, LNK2.2, LNK2.6, LNK-.1, LNK_BUCK.2, R5.2
link/dcc-de: DCC_SYNC.5, R6.1
link/fdcan.rx: CAN.3, STM32.62
link/fdcan.tx: CAN.2, STM32.63
link/jacks/CANH: CAN.6, LNK1.4, LNK2.4
link/jacks/CANL: CAN.5, LNK1.5, LNK2.5
link/jacks/DCC_A: DCC_SYNC.12, LNK1.7, LNK2.7
link/jacks/DCC_B: DCC_SYNC.13, LNK1.8, LNK2.8
nALERT: MON.3, R2.1, STM32.58
nrst: C24.1, STM32.12, SWD.3
swd/swd.swclk: STM32.46, SWD.2
swd/swd.swdio: STM32.45, SWD.1
track/VREF: C11.1, C12.1, R3.2, R4.1, U2.5, U6.5, U10.5, U14.5, U18.5, U22.5, U26.5, U30.5, VREF.1
track/VTRK: C7.1, C8.1, C9.1, C10.1, C29.1, C31.1, C38.1, C40.1, C47.1, C49.1, C56.1, C58.1, C65.1, C67.1, C74.1, C76.1, C83.1, C85.1, C92.1, C94.1, MON.8, MON.9, R1.2, U2.11, U6.11, U10.11, U14.11, U18.11, U22.11, U26.11, U30.11, VTRK.1
track/i2c.scl: MON.5, R9.1, SCL.1, STM32.60, TEMP0.2, TEMP1.2
track/i2c.sda: MON.4, R8.1, SDA.1, STM32.61, TEMP0.1, TEMP1.1
track/logic.rail: 3V3_BUCK.3, C5.2, C6.1, C13.1, C14.1, C17.1, C20.1, C22.1, C23.1, C25.1, C26.1, C27.1, C28.1, C32.1, C35.1, C36.1, C41.1, C44.1, C45.1, C50.1, C53.1, C54.1, C59.1, C62.1, C63.1, C68.1, C71.1, C72.1, C77.1, C80.1, C81.1, C86.1, C89.1, C90.1, C95.1, C98.1, C99.1, CAN.1, DCC_SYNC.1, DCC_SYNC.6, MON.1, MON.6, R2.2, R3.1, R8.2, R9.2, R11.2, R18.2, R25.2, R32.2, R39.2, R46.2, R53.2, R60.2, REG.2, STM32.6, STM32.7, STM32.8, SWD.4, TEMP0.8, TEMP1.7, TEMP1.8, U3.5, U4.5, U5.5, U7.5, U8.5, U9.5, U11.5, U12.5, U13.5, U15.5, U16.5, U17.5, U19.5, U20.5, U21.5, U23.5, U24.5, U25.5, U27.5, U28.5, U29.5, U31.5, U32.5, U33.5, Y1.1, Y1.4

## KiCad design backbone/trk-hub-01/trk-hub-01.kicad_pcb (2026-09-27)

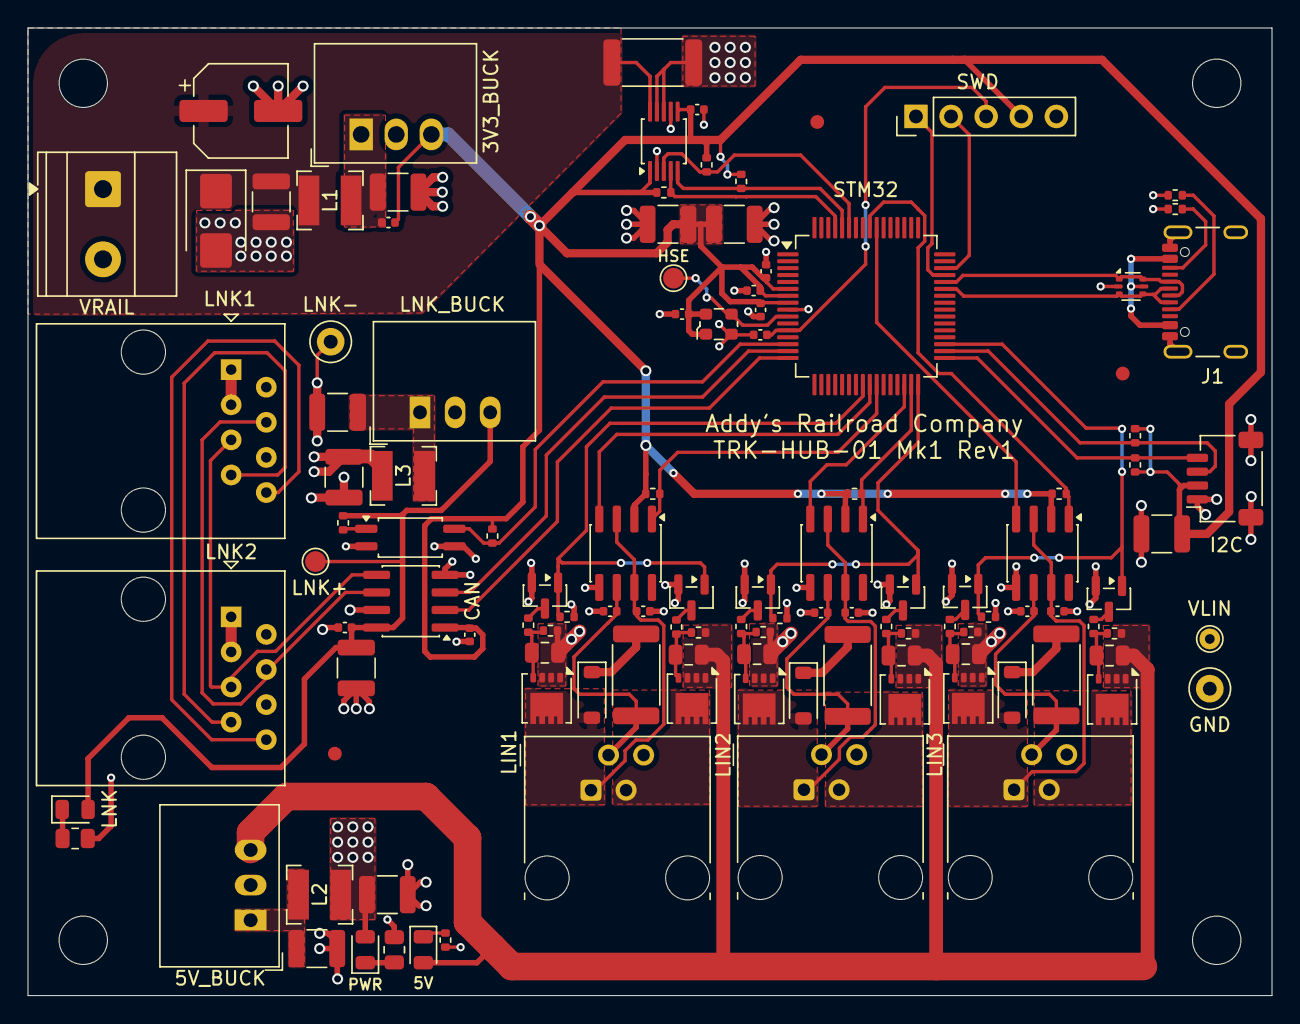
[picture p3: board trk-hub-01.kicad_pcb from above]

Board: 4 copper layers, 90.0 x 70.0 mm, 121 parts (0 on the bottom side), 69 nets.

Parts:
3V3_BUCK: R-78K3.3-0.5; Converter_DCDC_RECOM_R-78K-0.5_THT
5V: green; LED_0805_2012Metric
5V_BUCK: R-78E5.0-0.5; Converter_DCDC_RECOM_R-78E-0.5_THT
C1: 47µF; CP_Elec_6.3x7.7
C2, C10, C14, C18, C22, C23, C25, C27, C28, C30, C31: 100nF; C_0402_1005Metric
C3, C4, C6, C20, C32: 10µF; C_1210_3225Metric
C5, C11, C15, C19: 1nF; C_0402_1005Metric
C7, C21, C24, C26: 4.7µF; C_1210_3225Metric
C8, C9, C12, C13, C16, C17: 1µF; C_0805_2012Metric
C29: 1µF; C_1210_3225Metric
CAN: ISO1044BD; SOIC-8_3.9x4.9mm_P1.27mm
D1: SMBJ18A; D_SMB
D2, D3, D4: 1N4148W; D_SOD-123
FID1, FID2, FID3: Fiducial; Fiducial_1mm_Mask2mm
GND: TestPoint; TestPoint_Loop_D2.50mm_Drill1.0mm
H1, H2, H3, H4: MountingHole; MountingHole_3.5mm
HSE: TestPoint; TestPoint_Pad_D1.5mm
I2C: Conn_01x04_MountingPin; JST_SH_SM04B-SRSS-TB_1x04-1MP_P1.00mm_Horizontal
J1: USB_C_Receptacle_USB2.0_16P; USB_C_Receptacle_GCT_USB4105-xx-A_16P_TopMnt_Horizontal
L1: 100µH; L_Bourns-SRN4018
L2, L3: 15µH; L_Bourns-SRN4018
LIN1, LIN2, LIN3: RJ11; RJ11_Stewart_SS-90000-006_Horizontal
LNK: green; LED_0805_2012Metric
LNK1, LNK2: RJ45; RJ45_Amphenol_54602-x08_Horizontal
LNK+: TestPoint; TestPoint_Pad_D1.5mm
LNK-: TestPoint; TestPoint_Loop_D2.50mm_Drill1.0mm
LNK_BUCK: R-78E5.0-0.5; Converter_DCDC_RECOM_R-78E-0.5_THT
MON: INA226; TSSOP-10_3x3mm_P0.5mm
PWR: green; LED_0805_2012Metric
Q1, Q3, Q5, Q7, Q9, Q11: DMP3013SFV; Diodes_PowerDI3333-8
Q2, Q4, Q6, Q8, Q10, Q12: BSS138; SOT-23
R1: 20mΩ; R_2512_6332Metric
R2: 1kΩ; R_0402_1005Metric
R3: 5.1kΩ; R_0805_2012Metric
R4: 300Ω; R_0402_1005Metric
R5, R8, R12, R15, R19, R22: 49.9kΩ; R_0402_1005Metric
R6, R9, R13, R16, R20, R23, R29, R30: 5.1kΩ; R_0402_1005Metric
R7, R14, R21, R28: 100kΩ; R_0402_1005Metric
R10, R17, R24: 10kΩ; R_0402_1005Metric
R11, R18, R25: 1kΩ; R_2512_6332Metric
R26: 300Ω; R_0805_2012Metric
R27: 2kΩ; R_0402_1005Metric
R31, R32, R33, R34: 4.7kΩ; R_0402_1005Metric
STM32: STM32G0B1RETx; LQFP-64_10x10mm_P0.5mm
SWD: Conn_01x05; PinHeader_1x05_P2.54mm_Vertical
U1, U2, U3: NCV7321D12R2G; SOIC-8_3.9x4.9mm_P1.27mm
U4: FODM217A; SOP-4_4.4x2.6mm_P1.27mm
U5: USBLC6-2P6; SOT-666
VLIN: TestPoint; TestPoint_THTPad_D1.5mm_Drill0.7mm
VRAIL: Conn_01x02; TerminalBlock_Phoenix_MKDS-1,5-2-5.08_1x02_P5.08mm_Horizont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
Y1: 40MHz; Oscillator_SMD_ECS_2520MV-xxx-xx-4Pin_2.5x2.0mm

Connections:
3V3: 3V3_BUCK.3, C2.1, C5.2, C22.1, C25.1, C26.1, C28.1, C29.1, C30.1, C31.1, C32.1, CAN.1, I2C.2, MON.1, MON.6, R2.2, R10.2, R17.2, R24.2, R28.2, R31.2, R32.2, R33.2, R34.2, STM32.6, STM32.7, STM32.8, SWD.4, U1.2, U2.2, U3.2, Y1.1, Y1.4
unnamed: 3V3_BUCK.1, C4.1, C5.1, L1.2
unnamed: 5V.1, R4.1
unnamed: 5V_BUCK.1, C7.1, L2.2
unnamed: LNK.1, R26.1
unnamed: C21.1, L3.2, LNK_BUCK.1
unnamed: PWR.1, R3.1
unnamed: R27.2, U4.1
V5: 5V.2, 5V_BUCK.3, C9.2, C13.2, C17.2, Q3.1, Q3.2, Q3.3, Q7.1, Q7.2, Q7.3, Q11.1, Q11.2, Q11.3, R8.2, R15.2, R22.2
VBUS: J1.A4, J1.A9, J1.B4, J1.B9, U5.5
can/rxd: CAN.3, STM32.15
can/txd: CAN.2, STM32.16
expansion/scl: I2C.4, R34.1, STM32.33
expansion/sda: I2C.3, R33.1, STM32.34
hse: HSE.1, STM32.10, Y1.3
leg0/EN: Q2.1, Q4.1, R7.1, STM32.24
leg0/LIN: C11.1, LIN1.2, R11.2, U1.6
leg0/V5: LIN1.3, Q3.5
leg0/VPWR: C10.1, D2.2, LIN1.1, Q1.5, U1.3, U1.7
leg0/rxd: R10.1, STM32.26, U1.1
leg0/switch5/GATE: C9.1, Q3.4, R8.1, R9.2
leg0/switch5/drive: Q4.3, R9.1
leg0/switch/GATE: C8.1, Q1.4, R5.1, R6.2
leg0/switch/drive: Q2.3, R6.1
leg0/term/K: D2.1, R11.1
leg0/txd: STM32.25, U1.4
leg1/EN: Q6.1, Q8.1, R14.1, STM32.32
leg1/LIN: C15.1, LIN2.2, R18.2, U2.6
leg1/V5: LIN2.3, Q7.5
leg1/VPWR: C14.1, D3.2, LIN2.1, Q5.5, U2.3, U2.7
leg1/rxd: R17.1, STM32.31, U2.1
leg1/switch5/GATE: C13.1, Q7.4, R15.1, R16.2
leg1/switch5/drive: Q8.3, R16.1
leg1/switch/GATE: C12.1, Q5.4, R12.1, R13.2
leg1/switch/drive: Q6.3, R13.1
leg1/term/K: D3.1, R18.1
leg1/txd: STM32.30, U2.4
leg2/EN: Q10.1, Q12.1, R21.1, STM32.35
leg2/LIN: C19.1, LIN3.2, R25.2, U3.6
leg2/V5: LIN3.3, Q11.5
leg2/VPWR: C18.1, D4.2, LIN3.1, Q9.5, U3.3, U3.7
leg2/rxd: R24.1, STM32.56, U3.1
leg2/switch5/GATE: C17.1, Q11.4, R22.1, R23.2
leg2/switch5/drive: Q12.3, R23.1
leg2/switch/GATE: C16.1, Q9.4, R19.1, R20.2
leg2/switch/drive: Q10.3, R20.1
leg2/term/K: D4.1, R25.1
leg2/txd: STM32.55, U3.4
link/V5_LINK: C23.1, C24.1, CAN.8, LNK.2, LNK+.1, LNK_BUCK.3, R27.1
link/VLINK: C20.1, L3.1, LNK1.1, LNK1.3, LNK2.1, LNK2.3
link/VLINK_GND: C20.2, C21.2, C23.2, C24.2, CAN.7, LNK1.2, LNK1.6, LNK2.2, LNK2.6, LNK-.1, LNK_BUCK.2, R26.2, U4.2
link/good: R28.1, STM32.14, U4.4
link/jacks/CANH: CAN.6, LNK1.4, LNK2.4
link/jacks/CANL: CAN.5, LNK1.5, LNK2.5
link/jacks/DCC_A: LNK1.7, LNK2.7
link/jacks/DCC_B: LNK1.8, LNK2.8
monitor/scl: MON.5, R32.1, STM32.60
monitor/sda: MON.4, R31.1, STM32.61
nALERT: MON.3, R2.1, STM32.59
nrst: C27.1, STM32.12, SWD.3
rail/GND: 3V3_BUCK.2, 5V_BUCK.2, C1.2, C2.2, C3.2, C4.2, C6.2, C7.2, C10.2, C11.2, C14.2, C15.2, C18.2, C19.2, C22.2, C25.2, C26.2, C27.2, C28.2, C29.2, C30.2, C31.2, C32.2, CAN.4, D1.2, GND.1, I2C.1, I2C.MP, J1.A1, J1.A12, J1.B1, J1.B12, J1.SH, LIN1.4, LIN2.4, LIN3.4, MON.2, MON.7, Q2.2, Q4.2, Q6.2, Q8.2, Q10.2, Q12.2, R3.2, R4.2, R7.2, R14.2, R21.2, R29.2, R30.2, STM32.9, SWD.5, U1.5, U2.5, U3.5, U4.3, U5.2, VRAIL.2, Y1.2
rail/VLIN: C6.1, C8.2, C12.2, C16.2, L2.1, MON.8, MON.9, PWR.2, Q1.1, Q1.2, Q1.3, Q5.1, Q5.2, Q5.3, Q9.1, Q9.2, Q9.3, R1.2, R5.2, R12.2, R19.2, VLIN.1
rail/VPWR: C1.1, C3.1, D1.1, L1.1, MON.10, R1.1, VRAIL.1
swd/swclk: STM32.46, SWD.2
swd/swdio: STM32.45, SWD.1
usb/cc1: J1.A5, R29.1
usb/cc2: J1.B5, R30.1
usb/d+: J1.A6, J1.B6, STM32.44, U5.1, U5.6
usb/d-: J1.A7, J1.B7, STM32.43, U5.3, U5.4

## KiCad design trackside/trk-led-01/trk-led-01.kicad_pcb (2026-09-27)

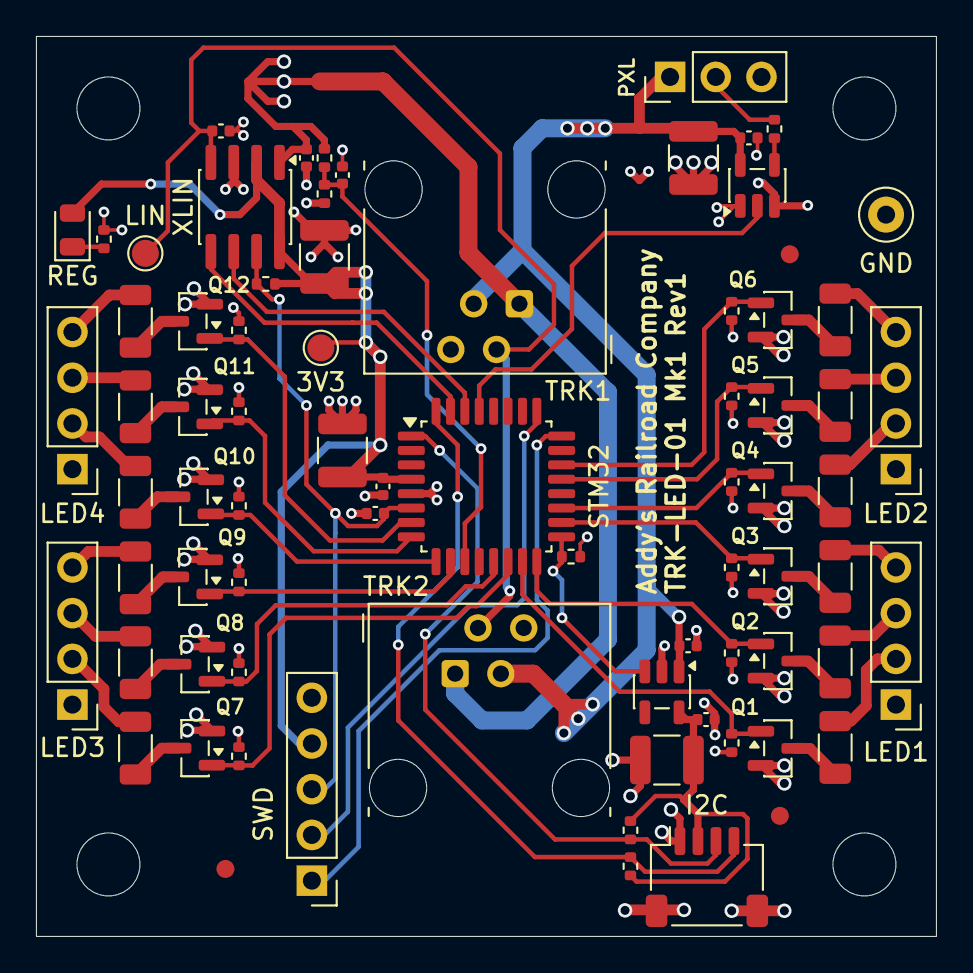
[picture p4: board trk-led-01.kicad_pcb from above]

Board: 4 copper layers, 50.0 x 50.0 mm, 80 parts (0 on the bottom side), 55 nets.

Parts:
3V3: TestPoint; TestPoint_Pad_D1.5mm
C1, C4, C6, C7, C9: 100nF; C_0402_1005Metric
C2, C5, C12: 10µF; C_1210_3225Metric
C3: 220pF; C_0402_1005Metric
C8: 4.7µF; C_1210_3225Metric
C10, C11: 1µF; C_0402_1005Metric
FID1, FID2, FID3: Fiducial; Fiducial_1mm_Mask2mm
GND: TestPoint; TestPoint_Loop_D2.50mm_Drill1.0mm
H1, H2, H3, H4: MountingHole; MountingHole_3.5mm
I2C: Conn_01x04_MountingPin; JST_SH_SM04B-SRSS-TB_1x04-1MP_P1.00mm_Horizontal
LED1, LED2, LED3, LED4: Conn_01x04; PinHeader_1x04_P2.54mm_Vertical
LIN: TestPoint; TestPoint_Pad_D1.5mm
PXL: Conn_01x03; PinHeader_1x03_P2.54mm_Vertical
Q1, Q2, Q3, Q4, Q5, Q6, Q7, Q8, Q9, Q10, Q11, Q12: DMN3404L; SOT-23
R1: 10kΩ; R_0402_1005Metric
R2: 330Ω; R_0402_1005Metric
R3, R5, R7, R9, R11, R13, R15, R17, R19, R21, R23, R25, R27, R30: 100kΩ; R_0402_1005Metric
R4, R6, R8, R10, R12, R14, R16, R18, R20, R22, R24, R26: 4.3kΩ; R_1206_3216Metric
R28: 18kΩ; R_0402_1005Metric
R29: 680Ω; R_0402_1005Metric
R31, R32: 4.7kΩ; R_0402_1005Metric
REG: green; LED_0805_2012Metric
STM32: STM32C092KBTx; LQFP-32_7x7mm_P0.8mm
SWD: Conn_01x05; PinHeader_1x05_P2.54mm_Vertical
TRK1, TRK2: RJ11; RJ11_Stewart_SS-90000-006_Horizontal
U1: 74AHCT1G125; SOT-23-5
U2: AP2112K-3.3; SOT-23-5
XLIN: NCV7428D13R2G; SOIC-8_3.9x4.9mm_P1.27mm

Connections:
unnamed: R29.1, REG.1
unnamed: R2.1, U1.4
unnamed: R30.1, STM32.17, U2.3
debug/swd.swclk: STM32.25, SWD.2
debug/swd.swdio: STM32.24, SWD.1
expansion/pulls/i2c.scl: I2C.4, R32.1, STM32.32
expansion/pulls/i2c.sda: I2C.3, R31.1, STM32.1
expansion/pulls/rail.rail: C11.1, C12.1, I2C.2, R31.2, R32.2, U2.5
head1/K1: LED1.2, R4.2
head1/K2: LED1.3, R6.2
head1/K3: LED1.4, R8.2
head1/gates.l1: Q1.1, R3.1, STM32.15
head1/gates.l2: Q2.1, R5.1, STM32.16
head1/gates.l3: Q3.1, R7.1, STM32.18
head1/l1/drain: Q1.3, R4.1
head1/l2/drain: Q2.3, R6.1
head1/l3/drain: Q3.3, R8.1
head2/K1: LED2.2, R10.2
head2/K2: LED2.3, R12.2
head2/K3: LED2.4, R14.2
head2/gates.l1: Q4.1, R9.1, STM32.19
head2/gates.l2: Q5.1, R11.1, STM32.21
head2/gates.l3: Q6.1, R13.1, STM32.22
head2/l1/drain: Q4.3, R10.1
head2/l2/drain: Q5.3, R12.1
head2/l3/drain: Q6.3, R14.1
head3/K1: LED3.2, R16.2
head3/K2: LED3.3, R18.2
head3/K3: LED3.4, R20.2
head3/gates.l1: Q7.1, R15.1, STM32.14
head3/gates.l2: Q8.1, R17.1, STM32.13
head3/gates.l3: Q9.1, R19.1, STM32.10
head3/l1/drain: Q7.3, R16.1
head3/l2/drain: Q8.3, R18.1
head3/l3/drain: Q9.3, R20.1
head4/K1: LED4.2, R22.2
head4/K2: LED4.3, R24.2
head4/K3: LED4.4, R26.2
head4/gates.l1: Q10.1, R21.1, STM32.9
head4/gates.l2: Q11.1, R23.1, STM32.8
head4/gates.l3: Q12.1, R25.1, STM32.7
head4/l1/drain: Q10.3, R22.1
head4/l2/drain: Q11.3, R24.1
head4/l3/drain: Q12.3, R26.1
node/GND: C1.2, C2.2, C3.2, C4.2, C5.2, C6.2, C7.2, C8.2, C9.2, C10.2, C11.2, C12.2, GND.1, I2C.1, I2C.MP, PXL.3, Q1.2, Q2.2, Q3.2, Q4.2, Q5.2, Q6.2, Q7.2, Q8.2, Q9.2, Q10.2, Q11.2, Q12.2, R3.2, R5.2, R7.2, R9.2, R11.2, R13.2, R15.2, R17.2, R19.2, R21.2, R23.2, R25.2, R28.2, R29.2, R30.2, STM32.5, SWD.5, TRK1.4, TRK2.4, U1.1, U1.3, U2.2, XLIN.3
node/LIN: C3.1, LIN.1, TRK1.2, TRK2.2, XLIN.4
node/V5: C4.1, C5.1, C10.1, PXL.1, TRK1.3, TRK2.3, U1.5, U2.1
node/VPWR: C1.1, LED1.1, LED2.1, LED3.1, LED4.1, R27.1, TRK1.1, TRK2.1, XLIN.1
node/link.rx: STM32.30, XLIN.6
node/link.tx: STM32.31, XLIN.5
node/v3v3.rail: 3V3.1, C2.1, C7.1, C8.1, R1.2, REG.2, STM32.4, SWD.4, XLIN.2, XLIN.8
nrst: C9.1, R1.1, STM32.6, SWD.3, XLIN.7
pixels/DOUT: PXL.2, R2.2
pixels/data: STM32.29, U1.2
sense/tap: C6.1, R27.2, R28.1, STM32.11

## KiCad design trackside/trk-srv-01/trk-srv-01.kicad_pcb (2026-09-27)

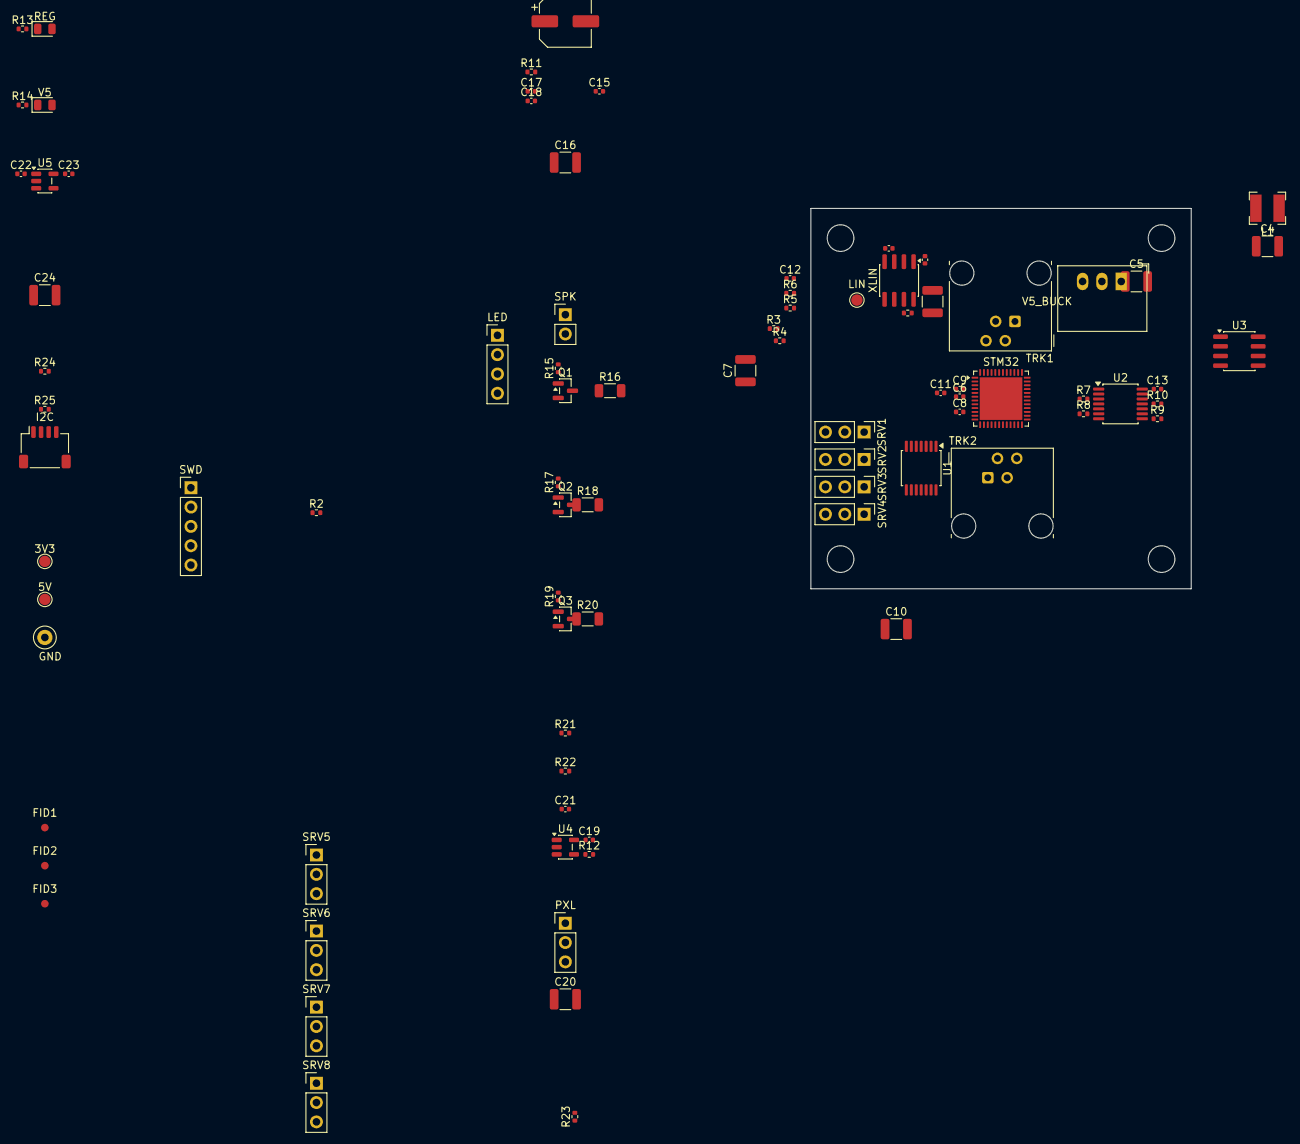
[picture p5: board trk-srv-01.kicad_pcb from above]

Board: 2 copper layers, 50.0 x 50.0 mm, 89 parts (0 on the bottom side), 54 nets, no tracks yet.

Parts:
3V3, 5V: TestPoint; TestPoint_Pad_D1.5mm
C1, C6, C8, C9, C11, C12, C13, C17, C18, C19, C21: 100nF; C_0402_1005Metric
C2, C4, C5, C16, C20, C24: 10µF; C_1210_3225Metric
C3: 220pF; C_0402_1005Metric
C7: 4.7µF; C_1210_3225Metric
C10: 1µF; C_1210_3225Metric
C14: 100µF; CP_Elec_6.3x5.8
C15, C22, C23: 1µF; C_0402_1005Metric
FID1, FID2, FID3: Fiducial; Fiducial_1mm_Mask2mm
GND: TestPoint; TestPoint_Loop_D2.50mm_Drill1.0mm
H1, H2, H3, H4: MountingHole; MountingHole_3.5mm
I2C: Conn_01x04_MountingPin; JST_SH_SM04B-SRSS-TB_1x04-1MP_P1.00mm_Horizontal
L1: 15µH; L_Bourns-SRN4018
LED: Conn_01x04; PinHeader_1x04_P2.54mm_Vertical
LIN: TestPoint; TestPoint_Pad_D1.5mm
PXL: Conn_01x03; PinHeader_1x03_P2.54mm_Vertical
Q1, Q2, Q3: DMN3404L; SOT-23
R1: 10kΩ; R_0402_1005Metric
R2, R3, R4, R5, R6, R7, R8, R9, R10, R11, R15, R17, R19, R21, R23: 100kΩ; R_0402_1005Metric
R12: 330Ω; R_0402_1005Metric
R13: 680Ω; R_0402_1005Metric
R14: 1.5kΩ; R_0402_1005Metric
R16, R18, R20: 4.3kΩ; R_1206_3216Metric
R22: 18kΩ; R_0402_1005Metric
R24, R25: 4.7kΩ; R_0402_1005Metric
REG: green; LED_0805_2012Metric
SPK: Conn_01x02; PinHeader_1x02_P2.54mm_Vertical
SRV1, SRV2, SRV3, SRV4, SRV5, SRV6, SRV7, SRV8: Conn_01x03; PinHeader_1x03_P2.54mm_Vertical
STM32: STM32G0B1CEUx; QFN-48-1EP_7x7mm_P0.5mm_EP5.6x5.6mm
SWD: Conn_01x05; PinHeader_1x05_P2.54mm_Vertical
TRK1, TRK2: RJ11; RJ11_Stewart_SS-90000-006_Horizontal
U1, U2: 74AHCT125; TSSOP-14_4.4x5mm_P0.65mm
U3: PAM8302AAD; SOIC-8_3.9x4.9mm_P1.27mm
U4: 74AHCT1G125; SOT-23-5
U5: AP2112K-3.3; SOT-23-5
V5: green; LED_0805_2012Metric
V5_BUCK: R-78E5.0-1.0; Converter_DCDC_RECOM_R-78E-0.5_THT
XLIN: NCV7428D13R2G; SOIC-8_3.9x4.9mm_P1.27mm

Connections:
unnamed: R13.1, REG.1
unnamed: R3.1, SRV1.1, U1.3
unnamed: R4.1, SRV2.1, U1.6
unnamed: R5.1, SRV3.1, U1.8
unnamed: R6.1, SRV4.1, U1.11
unnamed: R7.1, SRV5.1, U2.3
unnamed: R8.1, SRV6.1, U2.6
unnamed: R9.1, SRV7.1, U2.8
unnamed: R10.1, SRV8.1, U2.11
unnamed: C17.2, U3.3
unnamed: C18.2, U3.4
unnamed: R12.1, U4.4
unnamed: R23.1, STM32.21, U5.3
unnamed: R14.1, V5.1
bell/OUT+: SPK.1, U3.5
bell/OUT-: SPK.2, U3.8
bell/enable: R11.1, STM32.25, U3.1
bell/in: C17.1, STM32.15
expansion/pulls/i2c.scl: I2C.4, R25.1, STM32.47
expansion/pulls/i2c.sda: I2C.3, R24.1, STM32.48
expansion/pulls/rail.rail: C23.1, C24.1, I2C.2, R24.2, R25.2, U5.5
lamp1/drain: Q1.3, R16.1
lamp1/gate: Q1.1, R15.1, STM32.28
lamp2/drain: Q2.3, R18.1
lamp2/gate: Q2.1, R17.1, STM32.29
lamp3/drain: Q3.3, R20.1
lamp3/gate: Q3.1, R19.1, STM32.32
lamps/K1: LED.2, R16.2
lamps/K2: LED.3, R18.2
lamps/K3: LED.4, R20.2
lin/rxd: STM32.46, XLIN.5
lin/txd: STM32.45, XLIN.6
node/GND: C1.2, C2.2, C3.2, C4.2, C5.2, C6.2, C7.2, C8.2, C9.2, C10.2, C11.2, C12.2, C13.2, C14.2, C15.2, C16.2, C18.1, C19.2, C20.2, C21.2, C22.2, C23.2, C24.2, GND.1, I2C.1, I2C.MP, PXL.3, Q1.2, Q2.2, Q3.2, R3.2, R4.2, R5.2, R6.2, R7.2, R8.2, R9.2, R10.2, R11.2, R13.2, R14.2, R15.2, R17.2, R19.2, R22.2, R23.2, SRV1.3, SRV2.3, SRV3.3, SRV4.3, SRV5.3, SRV6.3, SRV7.3, SRV8.3, STM32.7, STM32.49, SWD.5, TRK1.4, TRK2.4, U1.7, U2.7, U3.7, U4.1, U4.3, U5.2, V5_BUCK.2, XLIN.3
node/LIN: C3.1, LIN.1, TRK1.2, TRK2.2, XLIN.4
node/V5: TRK1.3, TRK2.3
node/VPWR: C1.1, C4.1, L1.1, LED.1, R21.1, TRK1.1, TRK2.1, XLIN.1
node/v3v3.rail: 3V3.1, C2.1, C6.1, C7.1, C9.1, C10.1, C11.1, R1.2, REG.2, STM32.4, STM32.5, STM32.6, SWD.4, XLIN.2, XLIN.8
nrst: C8.1, R1.1, STM32.10, SWD.3, XLIN.7
pixels/DOUT: PXL.2, R12.2
pixels/data: STM32.44, U4.2
sense/tap: C21.1, R21.2, R22.1, STM32.22
servos/enable: R2.1, STM32.24, U1.1, U1.4, U1.10, U1.13, U2.1, U2.4, U2.10, U2.13
servos/p1: STM32.11, U1.2
servos/p2: STM32.12, U1.5
servos/p3: STM32.13, U1.9
servos/p4: STM32.14, U1.12
servos/p5: STM32.17, U2.2
servos/p6: STM32.18, U2.5
servos/p7: STM32.19, U2.9
servos/p8: STM32.20, U2.12
swd/swd.swclk: STM32.36, SWD.2
swd/swd.swdio: STM32.35, SWD.1
v5/filtered.rail: C5.1, L1.2, V5_BUCK.1
v5/out.rail: 5V.1, C12.1, C13.1, C14.1, C15.1, C16.1, C19.1, C20.1, C22.1, PXL.1, R2.2, SRV1.2, SRV2.2, SRV3.2, SRV4.2, SRV5.2, SRV6.2, SRV7.2, SRV8.2, U1.14, U2.14, U3.6, U4.5, U5.1, V5.2, V5_BUCK.3

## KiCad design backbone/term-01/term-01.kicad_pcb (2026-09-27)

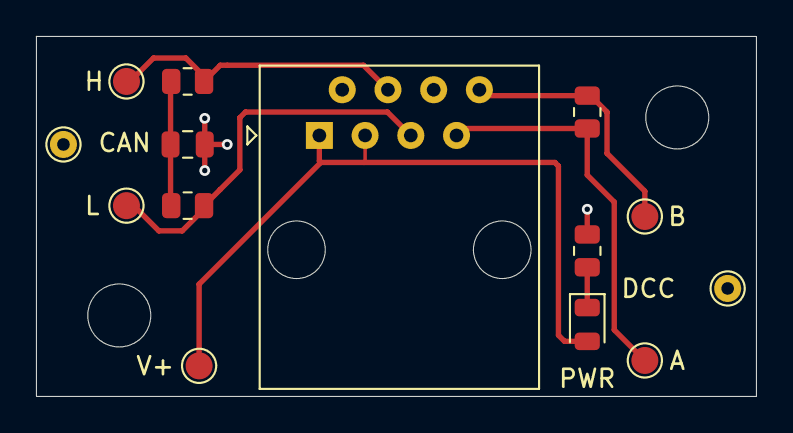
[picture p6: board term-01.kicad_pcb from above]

Board: 2 copper layers, 40.0 x 20.0 mm, 16 parts (0 on the bottom side), 8 nets.

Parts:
A: TestPoint; TestPoint_Pad_D1.5mm
B: TestPoint; TestPoint_Pad_D1.5mm
C1: 4.7nF; C_0805_2012Metric
H: TestPoint; TestPoint_Pad_D1.5mm
H1, H2: MountingHole; MountingHole_3.5mm
L: TestPoint; TestPoint_Pad_D1.5mm
LNK: RJ45; RJ45_Amphenol_54602-x08_Horizontal
PWR: green; LED_0805_2012Metric
R1, R2: 62Ω; R_0805_2012Metric
R3: 120Ω; R_0805_2012Metric
R4: 5.1kΩ; R_0805_2012Metric
TP1, TP2: TestPoint; TestPoint_THTPad_D1.5mm_Drill0.7mm
V+: TestPoint; TestPoint_Pad_D1.5mm

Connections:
CANH: H.1, LNK.4, R1.1
CANL: L.1, LNK.5, R2.2
CAN_MID: C1.1, R1.2, R2.1
DCC_A: A.1, LNK.7, R3.1
DCC_B: B.1, LNK.8, R3.2
unnamed: PWR.1, R4.1
entry/VLINK: LNK.1, LNK.3, PWR.2, V+.1
entry/VLINK_GND: C1.2, LNK.2, LNK.6, R4.2, TP1.1, TP2.1

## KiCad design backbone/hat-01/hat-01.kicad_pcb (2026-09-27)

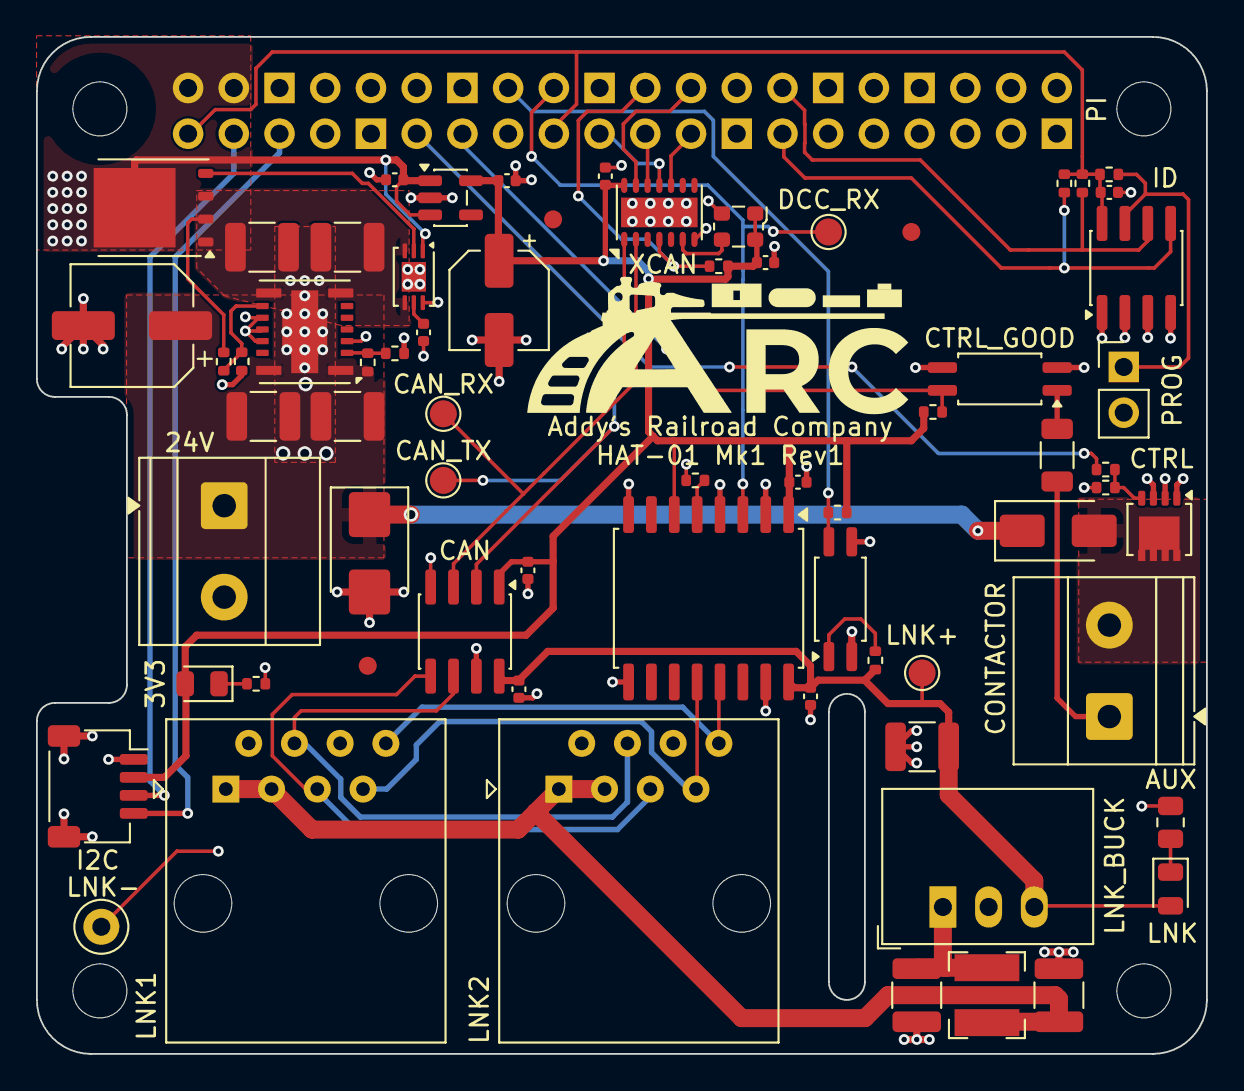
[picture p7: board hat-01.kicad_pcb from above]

Board: 4 copper layers, 65.0 x 56.5 mm, 69 parts (0 on the bottom side), 43 nets.

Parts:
3V3: green; LED_0805_2012Metric
24V: Conn_01x02; TerminalBlock_Phoenix_MKDS-1,5-2-5.08_1x02_P5.08mm_Horizont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
C1, C11, C12, C15, C16, C18, C19: 100nF; C_0402_1005Metric
C2: 47µF; CP_Elec_6.3x7.7
C3, C4, C13: 10µF; C_1210_3225Metric
C5, C6: 47µF; C_1210_3225Metric
C7: 10nF; C_0402_1005Metric
C8, C9: 1µF; C_0402_1005Metric
C10: 10µF; CP_Elec_5x5.8
C14, C17: 4.7µF; C_1210_3225Metric
CAN: ISO1044BD; SOIC-8_3.9x4.9mm_P1.27mm
CAN_RX: TestPoint; TestPoint_Pad_D1.5mm
CAN_TX: TestPoint; TestPoint_Pad_D1.5mm
CONTACTOR: Conn_01x02; TerminalBlock_Phoenix_MKDS-1,5-2-5.08_1x02_P5.08mm_Horizont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
CTRL: BUK9M53-60EX; LFPAK33
CTRL_GOOD: FODM217A; SOP-4_4.4x2.6mm_P1.27mm
D1: SMBJ26A; D_SMB
D2: SS16; D_SMA
DCC_RX: TestPoint; TestPoint_Pad_D1.5mm
DCC_SYNC: ISO1430DW; SOIC-16W_7.5x10.3mm_P1.27mm
FID1, FID2, FID3: Fiducial; Fiducial_1mm_Mask2mm
I2C: Conn_01x04_MountingPin; JST_SH_SM04B-SRSS-TB_1x04-1MP_P1.00mm_Horizontal
ID: CAT24C256; SOIC-8_3.9x4.9mm_P1.27mm
L1: 15µH; L_Bourns-SRN4018
LNK: green; LED_0805_2012Metric
LNK1, LNK2: RJ45; RJ45_Amphenol_54602-x08_Horizontal
LNK+: TestPoint; TestPoint_Pad_D1.5mm
LNK-: TestPoint; TestPoint_Loop_D2.50mm_Drill1.0mm
LNK_BUCK: R-78E5.0-0.5; Converter_DCDC_RECOM_R-78E-0.5_THT
PI: RPi_GPIO; RPI_Hat_B+
PROG: Conn_01x02; PinHeader_1x02_P2.54mm_Vertical
Q1: BSC030N08NS5; TDSON-8-1
R1, R4, R11, R15: 10kΩ; R_0402_1005Metric
R2, R3, R9: 4.7kΩ; R_0402_1005Metric
R5: 2.44kΩ; R_0402_1005Metric
R6, R13, R17: 100kΩ; R_0402_1005Metric
R7: 6.92kΩ; R_0402_1005Metric
R8: 680Ω; R_0402_1005Metric
R10: 300Ω; R_0805_2012Metric
R12: 2kΩ; R_0402_1005Metric
R14: 100Ω; R_0402_1005Metric
R16: 4.3kΩ; R_1206_3216Metric
U1: TPSM53603RDA; Texas_B3QFN-14-1EP_5x5.5mm_P0.65mm
U2: LTC4359-DCB; DFN-6-1EP_3x2mm_P0.5mm_EP1.65x1.35mm
U3: AP2112K-3.3; SOT-23-5
U4: FODM217A; SOP-4_4.4x2.6mm_P1.27mm
XCAN: MCP2518FD-xQBB; DFN-14-1EP_3x4.5mm_P0.65mm_EP1.65x4.25mm
Y1: 40MHz; Oscillator_SMD_ECS_2520MV-xxx-xx-4Pin_2.5x2.0mm

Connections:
3V3: 3V3.2, C9.1, C10.1, C11.1, C12.1, C15.1, C18.1, CAN.1, DCC_SYNC.1, DCC_SYNC.6, I2C.2, R9.2, R13.2, R17.2, U3.5, XCAN.14, Y1.1, Y1.4
unnamed: 3V3.1, R8.1
unnamed: CONTACTOR.1, R16.1
unnamed: CONTACTOR.2, CTRL.5, D2.2
unnamed: CTRL.4, R14.2, R15.1
unnamed: CTRL_GOOD.1, R16.2
unnamed: ID.7, PROG.1, R1.1
unnamed: LNK.1, R10.1
unnamed: C14.1, L1.2, LNK_BUCK.1
unnamed: R6.2, R7.1, U1.2
unnamed: R4.2, R5.1, U1.9
unnamed: Q1.4, U2.2
unnamed: C7.1, U2.5
unnamed: R12.2, U4.1
unnamed: XCAN.6, Y1.3
V5: C8.1, PI.2, PI.4, Q1.5, U2.1, U3.1, U3.3
VCC_ID: C1.1, ID.8, PI.1, PI.17, R1.2, R2.2, R3.2
VCTL: 24V.1, C2.1, C3.1, C4.1, D1.1, D2.1, R6.1, U1.1, U1.14
buck/out.rail: C5.1, C6.1, Q1.1, Q1.2, Q1.3, R4.1, U1.7, U1.8, U2.3, U2.4
host/can-int: PI.22, R9.1, XCAN.4
host/contactor-aux: CTRL_GOOD.4, PI.13, R17.1
host/contactor-en: PI.11, R14.1
host/dcc-rxd: DCC_RX.1, DCC_SYNC.3, PI.18
host/id-power.gnd: 24V.2, C1.2, C2.2, C3.2, C4.2, C5.2, C6.2, C7.2, C8.2, C9.2, C10.2, C11.2, C12.2, C15.2, C18.2, CAN.4, CTRL.1, CTRL.2, CTRL.3, CTRL_GOOD.2, CTRL_GOOD.3, D1.2, DCC_SYNC.2, DCC_SYNC.4, DCC_SYNC.8, I2C.1, I2C.MP, ID.1, ID.2, ID.3, ID.4, PI.6, PI.9, PI.14, PI.20, PI.25, PI.30, PI.34, PI.39, PROG.2, R5.2, R7.2, R8.2, R11.2, R15.2, U1.3, U1.10, U1.11, U1.12, U1.15, U2.6, U2.7, U3.2, U4.3, XCAN.7, XCAN.15, Y1.2
host/id/i2c.scl: ID.6, PI.28, R3.1
host/id/i2c.sda: ID.5, PI.27, R2.1
host/link-good: PI.16, R13.1, U4.4
host/scl: I2C.4, PI.5
host/sda: I2C.3, PI.3
host/spi-cs: PI.24, XCAN.13
host/spi-miso: PI.21, XCAN.12
host/spi-mosi: PI.19, XCAN.11
host/spi-sck: PI.23, XCAN.10
link/V5_LINK: C16.1, C17.1, C19.1, CAN.8, DCC_SYNC.16, LNK.2, LNK+.1, LNK_BUCK.3, R12.1
link/VLINK: C13.1, L1.1, LNK1.1, LNK1.3, LNK2.1, LNK2.3
link/VLINK_GND: C13.2, C14.2, C16.2, C17.2, C19.2, CAN.7, DCC_SYNC.9, DCC_SYNC.15, LNK1.2, LNK1.6, LNK2.2, LNK2.6, LNK-.1, LNK_BUCK.2, R10.2, U4.2
link/dcc-de: DCC_SYNC.5, R11.1
link/fdcan.rx: CAN.3, CAN_RX.1, XCAN.2
link/fdcan.tx: CAN.2, CAN_TX.1, XCAN.1
link/jacks/CANH: CAN.6, LNK1.4, LNK2.4
link/jacks/CANL: CAN.5, LNK1.5, LNK2.5
link/jacks/DCC_A: DCC_SYNC.12, LNK1.7, LNK2.7
link/jacks/DCC_B: DCC_SYNC.13, LNK1.8, LNK2.8

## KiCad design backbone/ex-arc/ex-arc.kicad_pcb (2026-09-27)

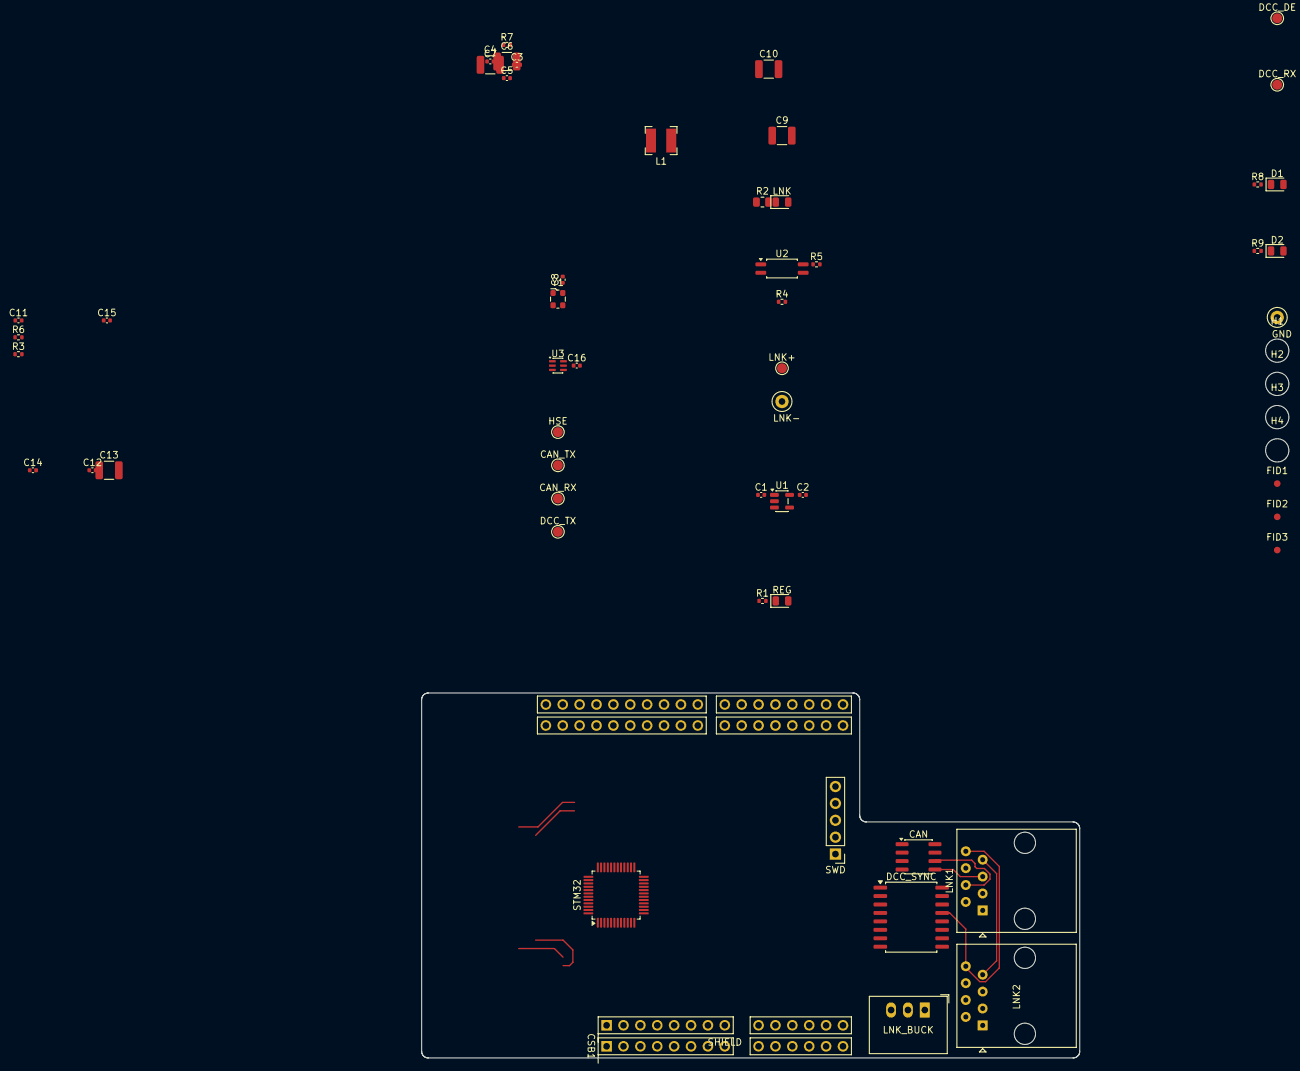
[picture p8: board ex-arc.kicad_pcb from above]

Board: 2 copper layers, 99.0 x 54.9 mm, 59 parts (0 on the bottom side), 58 nets.

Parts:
C1, C2: 1µF; C_0402_1005Metric
C3, C5, C7, C8, C11, C12, C14, C15, C16: 100nF; C_0402_1005Metric
C4, C10, C13: 4.7µF; C_1210_3225Metric
C6: 1µF; C_1210_3225Metric
C9: 10µF; C_1210_3225Metric
CAN: ISO1044BD; SOIC-8_3.9x4.9mm_P1.27mm
CAN_RX: TestPoint; TestPoint_Pad_D1.5mm
CAN_TX: TestPoint; TestPoint_Pad_D1.5mm
CSB1: Arduino_UNO_R3; Arduino_UNO_R3_Pins
D1, D2: red; LED_0805_2012Metric
DCC_DE: TestPoint; TestPoint_Pad_D1.5mm
DCC_RX: TestPoint; TestPoint_Pad_D1.5mm
DCC_SYNC: ISO1430DW; SOIC-16W_7.5x10.3mm_P1.27mm
DCC_TX: TestPoint; TestPoint_Pad_D1.5mm
FID1, FID2, FID3: Fiducial; Fiducial_1mm_Mask2mm
GND: TestPoint; TestPoint_Loop_D2.50mm_Drill1.0mm
H1, H2, H3, H4: MountingHole; MountingHole_3.5mm
HSE: TestPoint; TestPoint_Pad_D1.5mm
L1: 15µH; L_Bourns-SRN4018
LNK: green; LED_0805_2012Metric
LNK1, LNK2: RJ45; RJ45_Amphenol_54602-x08_Horizontal
LNK+: TestPoint; TestPoint_Pad_D1.5mm
LNK-: TestPoint; TestPoint_Loop_D2.50mm_Drill1.0mm
LNK_BUCK: R-78E5.0-0.5; Converter_DCDC_RECOM_R-78E-0.5_THT
R1: 680Ω; R_0402_1005Metric
R2: 300Ω; R_0805_2012Metric
R3, R7: 10kΩ; R_0402_1005Metric
R4: 2kΩ; R_0402_1005Metric
R5: 100kΩ; R_0402_1005Metric
R6: 33Ω; R_0402_1005Metric
R8, R9: 620Ω; R_0402_1005Metric
REG: green; LED_0805_2012Metric
SHIELD: Arduino_UNO_R3; Arduino_UNO_R3_Socket
STM32: STM32C092CBTx; LQFP-48_7x7mm_P0.5mm
SWD: Conn_01x05; PinHeader_1x05_P2.54mm_Vertical
U1: AP2112K-3.3; SOT-23-5
U2: FODM217A; SOP-4_4.4x2.6mm_P1.27mm
U3: 74LVC1G3157; SOT-363_SC-70-6
Y1: 40MHz; Oscillator_SMD_ECS_2520MV-xxx-xx-4Pin_2.5x2.0mm

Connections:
3V3: C2.1, C3.1, C4.1, C6.1, C7.1, C8.1, C11.1, C14.1, C16.1, CAN.1, D1.2, D2.2, DCC_SYNC.1, R5.2, REG.2, STM32.5, STM32.6, SWD.4, U1.5, U3.5, Y1.1, Y1.4
unnamed: CSB1.9, SHIELD.9
unnamed: CSB1.10, SHIELD.10
unnamed: CSB1.11, SHIELD.11
unnamed: CSB1.12, SHIELD.12
unnamed: CSB1.30, SHIELD.30
unnamed: CSB1.15, SHIELD.15
unnamed: CSB1.16, SHIELD.16
unnamed: CSB1.17, SHIELD.17
unnamed: CSB1.18, SHIELD.18
unnamed: CSB1.19, SHIELD.19
unnamed: CSB1.20, SHIELD.20
unnamed: CSB1.21, SHIELD.21
unnamed: CSB1.25, SHIELD.25
unnamed: CSB1.26, SHIELD.26
unnamed: CSB1.28, SHIELD.28
unnamed: CSB1.2, SHIELD.2
unnamed: CSB1.4, SHIELD.4
unnamed: CSB1.32, SHIELD.32
unnamed: CSB1.31, SHIELD.31
unnamed: CSB1.8, SHIELD.8
unnamed: D1.1, R8.1
unnamed: D2.1, R9.1
unnamed: DCC_RX.1, R6.2, STM32.30, U3.1
unnamed: LNK.1, R2.1
unnamed: C10.1, L1.2, LNK_BUCK.1
unnamed: R1.1, REG.1
unnamed: R8.2, STM32.22
unnamed: R9.2, STM32.23
unnamed: R4.2, U2.1
booster/input: CSB1.22, SHIELD.22, U3.4
booster/select: R7.1, STM32.27, U3.6
brake/c: SHIELD.24, STM32.43
brake/d: SHIELD.23, STM32.44
dcc/de: DCC_DE.1, DCC_SYNC.5, R3.1, STM32.1
dcc/rxd: DCC_SYNC.3, R6.1
dcc/txd: CSB1.27, DCC_SYNC.6, DCC_TX.1, SHIELD.27
fault/c: SHIELD.13, STM32.45
fault/d: SHIELD.14, STM32.46
host/reset: CSB1.3, SHIELD.3, STM32.24
host/rxd: CSB1.14, STM32.13
host/txd: CSB1.13, STM32.14
host/v5.gnd: C1.2, C2.2, C3.2, C4.2, C5.2, C6.2, C7.2, C8.2, C11.2, C14.2, C16.2, CAN.4, CSB1.6, CSB1.7, CSB1.29, DCC_SYNC.2, DCC_SYNC.4, DCC_SYNC.8, GND.1, R1.2, R3.2, R7.2, SHIELD.6, SHIELD.7, SHIELD.29, STM32.7, SWD.5, U1.2, U2.3, U3.2, Y1.2
host/v5.rail: C1.1, CSB1.5, SHIELD.5, U1.1, U1.3
hse: HSE.1, STM32.8, Y1.3
link/V5_LINK: C12.1, C13.1, C15.1, CAN.8, DCC_SYNC.16, LNK.2, LNK+.1, LNK_BUCK.3, R4.1
link/VLINK: C9.1, L1.1, LNK1.1, LNK1.3, LNK2.1, LNK2.3
link/VLINK_GND: C9.2, C10.2, C12.2, C13.2, C15.2, CAN.7, DCC_SYNC.9, DCC_SYNC.15, LNK1.2, LNK1.6, LNK2.2, LNK2.6, LNK-.1, LNK_BUCK.2, R2.2, U2.2
link/fdcan.rx: CAN.3, CAN_RX.1, STM32.38
link/fdcan.tx: CAN.2, CAN_TX.1, STM32.39
link/good: R5.1, STM32.25, U2.4
link/jacks/CANH: CAN.6, LNK1.4, LNK2.4
link/jacks/CANL: CAN.5, LNK1.5, LNK2.5
link/jacks/DCC_A: DCC_SYNC.12, LNK1.7, LNK2.7
link/jacks/DCC_B: DCC_SYNC.13, LNK1.8, LNK2.8
swd/swd.nrst: C5.1, STM32.10, SWD.3
swd/swd.swclk: STM32.36, SWD.2
swd/swd.swdio: STM32.35, SWD.1

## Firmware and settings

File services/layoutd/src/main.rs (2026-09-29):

use layoutd::{
    CanNetwork, Health, Index, Layout, LayoutStatus, NodeFact, NodeObservation, Publisher,
    SetNodeCommand, apply_command, check_command, command_topic, index_topic, publish_layout,
    publish_status, status_topic, topic_segment,
};
use rumqttc::{Client, Event, Incoming, LastWill, MqttOptions, QoS};
use serde::{Deserialize, Serialize};
use std::collections::BTreeMap;
use std::fs;
use std::io::Write;
use std::path::PathBuf;
use std::sync::mpsc::{self, Receiver};
use std::thread;
use std::time::{Duration, Instant};

#[path = "../../../firmware/shared/host_clock.rs"]
mod host_clock;
use host_clock::HostClock;

#[derive(Deserialize)]
struct SimulatedCanState {
    nodes: Vec<NodeObservation>,
}

struct SimulatedCan {
    path: PathBuf,
}

impl CanNetwork for SimulatedCan {
    fn observe(&mut self) -> Result<Vec<NodeObservation>, String> {
        let bytes = fs::read(&self.path).map_err(|error| error.to_string())?;
        let state: SimulatedCanState =
            serde_json::from_slice(&bytes).map_err(|error| error.to_string())?;
        Ok(state.nodes)
    }
    fn grant_dcc(&mut self, target: u32) -> Result<(), String> {
        let mut out = fs::OpenOptions::new()
            .create(true)
            .append(true)
            .open(self.path.with_extension("commands.jsonl"))
            .map_err(|e| e.to_string())?;
        writeln!(out, "{}", layoutd::can::grant_frame(target)?).map_err(|e| e.to_string())
    }
}

enum CanBackend {
    File(SimulatedCan),
    Tcp(layoutd::can::TcpCan),
}
impl CanNetwork for CanBackend {
    fn observe(&mut self) -> Result<Vec<NodeObservation>, String> {
        match self {
            Self::File(can) => can.observe(),
            Self::Tcp(can) => can.observe(),
        }
    }
    fn grant_dcc(&mut self, target: u32) -> Result<(), String> {
        match self {
            Self::File(can) => can.grant_dcc(target),
            Self::Tcp(can) => can.grant_dcc(target),
        }
    }
}

impl CanBackend {
    fn set_time(&mut self, now_ms: u64) {
        if let Self::Tcp(can) = self {
            can.set_time(now_ms);
        }
    }

    fn wait_marker(&self, now_ms: u64) {
        if let Self::Tcp(can) = self {
            can.wait_marker(now_ms);
        }
    }
}

enum BrokerEvent {
    Connected,
    Subscribed,
    Acknowledged,
    Failed(String),
}

struct Message {
    topic: String,
    payload: Vec<u8>,
    retained: bool,
}

struct Mqtt {
    client: Client,
    events: Receiver<BrokerEvent>,
    messages: Receiver<Message>,
}

impl Mqtt {
    fn connect(host: &str, port: u16, prefix: &str) -> Result<Self, String> {
        let mut options = MqttOptions::new(format!("arc-layoutd-{prefix}"), host, port);
        options.set_keep_alive(Duration::from_secs(5));
        let offline = serde_json::to_vec(&LayoutStatus {
            state: Health::Offline,
            reasons: vec!["layoutd disconnected".into()],
        })
        .map_err(|error| error.to_string())?;
        options.set_last_will(LastWill::new(
            status_topic(prefix),
            offline,
            QoS::AtLeastOnce,
            true,
        ));
        let (client, mut connection) = Client::new(options, 16);
        let (event_sender, events) = mpsc::channel();
        let (message_sender, messages) = mpsc::channel();
        thread::spawn(move || {
            for event in connection.iter() {
                let notification = match event {
                    Ok(Event::Incoming(Incoming::ConnAck(_))) => Some(BrokerEvent::Connected),
                    Ok(Event::Incoming(Incoming::SubAck(_))) => Some(BrokerEvent::Subscribed),
                    Ok(Event::Incoming(Incoming::PubAck(_))) => Some(BrokerEvent::Acknowledged),
                    Ok(Event::Incoming(Incoming::Publish(publish))) => {
                        if message_sender
                            .send(Message {
                                topic: publish.topic,
                                payload: publish.payload.to_vec(),
                                retained: publish.retain,
                            })
                            .is_err()
                        {
                            break;
                        }
                        None
                    }
                    Err(error) => Some(BrokerEvent::Failed(error.to_string())),
                    _ => None,
                };
                if let Some(notification) = notification
                    && event_sender.send(notification).is_err()
                {
                    break;
                }
            }
        });
        let mut mqtt = Self {
            client,
            events,
            messages,
        };
        mqtt.wait_for(
            |event| matches!(event, BrokerEvent::Connected),
            "connection",
        )?;
        for topic in [
            index_topic(prefix),
            format!("/{prefix}/layout/node/+/fact"),
            command_topic(prefix),
        ] {
            mqtt.client
                .subscribe(topic, QoS::AtLeastOnce)
                .map_err(|error| error.to_string())?;
            mqtt.wait_for(
                |event| matches!(event, BrokerEvent::Subscribed),
                "subscription",
            )?;
        }
        Ok(mqtt)
    }

    fn wait_for(
        &mut self,
        expected: impl Fn(&BrokerEvent) -> bool,
        context: &str,
    ) -> Result<(), String> {
        match self.events.recv_timeout(Duration::from_secs(10)) {
            Ok(event) if expected(&event) => Ok(()),
            Ok(BrokerEvent::Failed(error)) => Err(format!("MQTT {context}: {error}")),
            Ok(_) => Err(format!("unexpected MQTT event during {context}")),
            Err(error) => Err(format!("waiting for MQTT {context}: {error}")),
        }
    }

    fn publish(&mut self, topic: &str, payload: &[u8], retained: bool) -> Result<(), String> {
        self.client
            .publish(topic, QoS::AtLeastOnce, retained, payload)
            .map_err(|error| error.to_string())?;
        self.wait_for(|event| matches!(event, BrokerEvent::Acknowledged), "PUBACK")
    }

    fn check_connection(&mut self) -> Result<(), String> {
        if let Ok(event) = self.events.try_recv() {
            match event {
                BrokerEvent::Failed(error) => Err(format!("MQTT connection lost: {error}")),
                BrokerEvent::Connected => {
                    Err("MQTT reconnected; restart layoutd to rebuild retained state".into())
                }
                _ => Err("unexpected MQTT acknowledgement".into()),
            }
        } else {
            Ok(())
        }
    }
}

impl Publisher for Mqtt {
    fn publish_retained(&mut self, topic: &str, payload: &[u8]) -> Result<(), String> {
        self.publish(topic, payload, true)
    }
}

#[derive(Default)]
struct RetainedFacts {
    index: Option<Index>,
    facts: BTreeMap<String, NodeFact>,
}

impl RetainedFacts {
    fn ingest(&mut self, prefix: &str, message: &Message) -> Result<(), String> {
        if !message.retained {
            return Ok(());
        }
        if message.topic == index_topic(prefix) {
            self.index = Some(
                serde_json::from_slice(&message.payload)
                    .map_err(|error| format!("invalid retained index: {error}"))?,
            );
        } else if let Some(id) = message
            .topic
            .strip_prefix(&format!("/{prefix}/layout/node/"))
            .and_then(|suffix| suffix.strip_suffix("/fact"))
            && topic_segment(id)
        {
            if message.payload.is_empty() {
                self.facts.remove(id);
            } else {
                let fact: NodeFact = serde_json::from_slice(&message.payload)
                    .map_err(|error| format!("invalid retained fact for {id}: {error}"))?;
                self.facts.insert(id.into(), fact);
            }
        }
        Ok(())
    }

    fn layout(&self) -> Option<Layout> {
        let index = self.index.as_ref()?;
        let nodes = index
            .iter()
            .map(|id| self.facts.get(id).map(|fact| (id.clone(), fact.clone())))
            .collect::<Option<BTreeMap<_, _>>>()?;
        Some(Layout { nodes })
    }
}

#[derive(Serialize)]
struct CommandResult {
    request_id: Option<String>,
    accepted: bool,
    error: Option<String>,
}

fn send_result(mqtt: &mut Mqtt, prefix: &str, result: CommandResult) -> Result<(), String> {
    let payload = serde_json::to_vec(&result).map_err(|error| error.to_string())?;
    mqtt.publish(&format!("/{prefix}/layout/command/result"), &payload, false)
}

fn handle_command(
    mqtt: &mut Mqtt,
    can: &mut impl CanNetwork,
    prefix: &str,
    current: &mut Option<Layout>,
    published: &mut LayoutStatus,
    message: &Message,
) -> Result<(), String> {
    if message.retained {
        return Ok(());
    }
    let command: SetNodeCommand = match serde_json::from_slice(&message.payload) {
        Ok(command) => command,
        Err(error) => {
            return send_result(
                mqtt,
                prefix,
                CommandResult {
                    request_id: None,
                    accepted: false,
                    error: Some(format!("invalid command: {error}")),
                },
            );
        }
    };
    let error = check_command(current.as_ref(), &command).err();
    if let Some(error) = error {
        return send_result(
            mqtt,
            prefix,
            CommandResult {
                request_id: Some(command.request_id),
                accepted: false,
                error: Some(error),
            },
        );
    }
    let next = apply_command(current.as_ref(), &command);
    *published = publish_layout(mqtt, prefix, &next, current.as_ref(), can)?;
    *current = Some(next);
    send_result(
        mqtt,
        prefix,
        CommandResult {
            request_id: Some(command.request_id),
            accepted: true,
            error: None,
        },
    )
}

fn run() -> Result<(), String> {
    let args: Vec<_> = std::env::args().collect();
    if !(3..=5).contains(&args.len()) {
        return Err(
            "usage: layoutd <layout-prefix> <sim-can.json|tcp://host:port> [mqtt-host] [mqtt-port]"
                .into(),
        );
    }
    let prefix = &args[1];
    if !topic_segment(prefix) {
        return Err("layout prefix must be one MQTT topic segment".into());
    }
    let host = args.get(3).map(String::as_str).unwrap_or("127.0.0.1");
    let port = args
        .get(4)
        .map(|value| value.parse::<u16>())
        .transpose()
        .map_err(|error| error.to_string())?
        .unwrap_or(1883);
    let clock_address = std::env::var("ARC_SIM_CLOCK").ok().filter(|value| !value.is_empty());
    let mut clock = clock_address.as_deref().map(|address| HostClock::connect(address, "layoutd")).transpose()?;
    let mut can = if let Some(address) = args[2].strip_prefix("tcp://") {
        CanBackend::Tcp(layoutd::can::TcpCan::connect(address, clock.is_some())?)
    } else {
        CanBackend::File(SimulatedCan {
            path: PathBuf::from(&args[2]),
        })
    };
    let mut mqtt = Mqtt::connect(host, port, prefix)?;
    let mut published = LayoutStatus {
        state: Health::Updating,
        reasons: vec![],
    };
    publish_status(&mut mqtt, prefix, &published)?;
    let mut master = layoutd::master::Master::default();
    let mut published_master = None;
    mqtt.publish(&format!("/{prefix}/layout/dcc_master"), b"null", true)?;
    let started = Instant::now();
    let mut retained = RetainedFacts::default();
    let mut current: Option<Layout> = None;
    let mut bootstrap_complete = false;
    let bootstrap_deadline_ms = 2_000u64;
    eprintln!("layoutd: serving {prefix}");

    loop {
        mqtt.check_connection()?;
        let message = if clock.is_some() {
            mqtt.messages.try_recv().ok()
        } else {
            mqtt.messages.recv_timeout(Duration::from_millis(200)).ok()
        };
        if let Some(message) = &message {
            retained.ingest(prefix, message)?;
            if current.is_none()
                && let Some(layout) = retained.layout()
            {
                published = publish_layout(&mut mqtt, prefix, &layout, None, &mut can)?;
                current = Some(layout);
                bootstrap_complete = true;
            }
            if message.topic == command_topic(prefix) && !message.retained {
                if !bootstrap_complete {
                    send_result(
                        &mut mqtt,
                        prefix,
                        CommandResult {
                            request_id: None,
                            accepted: false,
                            error: Some("retained layout state is still loading; retry".into()),
                        },
                    )?;
                } else if current.is_none() && retained.index.is_some() {
                    send_result(
                        &mut mqtt,
                        prefix,
                        CommandResult {
                            request_id: None,
                            accepted: false,
                            error: Some("retained index references missing node facts".into()),
                        },
                    )?;
                } else {
                    handle_command(
                        &mut mqtt,
                        &mut can,
                        prefix,
                        &mut current,
                        &mut published,
                        message,
                    )?;
                }
            }
        }
        let elapsed = if let Some(clock) = &mut clock {
            let Some(now) = clock.wait()? else { continue };
            can.wait_marker(now);
            can.set_time(now);
            now
        } else {
            started.elapsed().as_millis() as u64
        };
        if !bootstrap_complete && elapsed >= bootstrap_deadline_ms {
            bootstrap_complete = true;
            published = LayoutStatus {
                state: Health::Invalid,
                reasons: vec![if retained.index.is_some() {
                    "retained index references missing node facts".into()
                } else {
                    "no retained layout index; waiting for the first command".into()
                }],
            };
            publish_status(&mut mqtt, prefix, &published)?;
        }
        if let Some(layout) = &current {
            let observation = can.observe();
            let status = layoutd::evaluate(
                layout,
                observation
                    .as_ref()
                    .map(Vec::as_slice)
                    .map_err(String::as_str),
            );
            if let Ok(nodes) = &observation {
                master.update(
                    &status,
                    nodes,
                    elapsed,
                    &mut can,
                )?;
                if master.selected() != published_master {
                    let payload =
                        serde_json::to_vec(&master.selected().map(|id| format!("{id:06x}")))
                            .map_err(|e| e.to_string())?;
                    mqtt.publish(&format!("/{prefix}/layout/dcc_master"), &payload, true)?;
                    published_master = master.selected();
                }
            }
            if status != published {
                publish_status(&mut mqtt, prefix, &status)?;
                published = status;
            }
        }
        if let Some(clock) = &mut clock {
            clock.ack()?;
        }
    }
}

fn main() {
    if let Err(error) = run() {
        eprintln!("layoutd: {error}");
        std::process::exit(1);
    }
}

#[cfg(test)]
mod tests {
    use super::*;
    use layoutd::{BoardEndpoint, Kind, NodeFact, Topology};

    #[test]
    fn index_waits_for_each_named_fact() {
        let fact = NodeFact {
            kind: Kind::District,
            topology: Topology::Configured {
                connections: vec![],
            },
            binding: Some(BoardEndpoint {
                node_id: "board".into(),
                output: 0,
            }),
        };
        let mut retained = RetainedFacts::default();
        retained
            .ingest(
                "test",
                &Message {
                    topic: index_topic("test"),
                    payload: serde_json::to_vec(&Index::from(["a".into(), "b".into()])).unwrap(),
                    retained: true,
                },
            )
            .unwrap();
        for id in ["a", "b"] {
            retained
                .ingest(
                    "test",
                    &Message {
                        topic: layoutd::fact_topic("test", id),
                        payload: serde_json::to_vec(&fact).unwrap(),
                        retained: true,
                    },
                )
                .unwrap();
            if id == "a" {
                assert!(retained.layout().is_none());
            }
        }
        assert_eq!(retained.layout().unwrap().nodes.len(), 2);
    }
}

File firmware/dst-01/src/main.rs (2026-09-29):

//! Embassy entry point for ARC-DST-01. Select `x4` and exactly one revision.

#![no_std]
#![no_main]

#[cfg(not(feature = "x4"))]
compile_error!("select the supported district variant with --features x4");
#[cfg(not(any(feature = "rev1", feature = "rev2")))]
compile_error!("select exactly one hardware revision: rev1 or rev2");
#[cfg(all(feature = "rev1", feature = "rev2"))]
compile_error!("rev1 and rev2 are mutually exclusive");

use dst_01::network::{self, StatusCadence};
use core::cell::RefCell;
#[cfg(feature = "rev1")]
use core::sync::atomic::{AtomicU8, Ordering};
use embassy_executor::Spawner;
use embassy_stm32::can::{CanRx, CanTx, frame::FdFrame};
use embassy_stm32::{flash::Flash, peripherals};
use embassy_sync::{blocking_mutex::{Mutex, raw::{CriticalSectionRawMutex, NoopRawMutex}}, channel::Channel};
use embassy_boot_stm32::{BlockingFirmwareUpdater, FirmwareUpdaterConfig};
#[cfg(feature = "rev1")]
use embassy_futures::select::{Either, select};
use embassy_time::{Duration, Instant, Timer};
use link::{Presence, update::{self, ImageKind, Phase, Status}};
use panic_halt as _;
#[cfg(feature = "rev1")]
mod usb_console;

mod hal;
#[path = "../../shared/update_receiver.rs"]
mod update_receiver;

static UPDATE_RESP: Channel<CriticalSectionRawMutex, Status, 4> = Channel::new();
#[cfg(feature = "rev1")]
static ERASE_REQUEST: Channel<CriticalSectionRawMutex, (), 1> = Channel::new();
#[cfg(feature = "rev1")]
static ERASE_RESPONSE: Channel<CriticalSectionRawMutex, EraseResult, 1> = Channel::new();
#[cfg(feature = "rev1")]
static LED_MODE: AtomicU8 = AtomicU8::new(dst_01::console::LedMode::Auto as u8);

#[cfg(feature = "rev1")]
#[derive(Clone, Copy)]
enum EraseResult {
    Erased,
    BootLocked,
    Failed,
}

#[embassy_executor::task(pool_size = 4)]
async fn district_task(hal: hal::District, control: &'static dst_01::tasks::Control) {
    dst_01::tasks::run(hal, control).await;
}

#[cfg(feature = "rev1")]
#[embassy_executor::task]
async fn rgb_blink_task(mut led: hal::RgbLed) {
    // Three primaries, their pairs, and white; both LEDs blink together.
    const COLORS: [(bool, bool, bool); 7] = [
        (true, false, false),
        (false, true, false),
        (false, false, true),
        (true, true, false),
        (false, true, true),
        (true, false, true),
        (true, true, true),
    ];
    let mut phase: usize = 0;
    loop {
        let mode = dst_01::console::LedMode::from_u8(LED_MODE.load(Ordering::Relaxed));
        let color = if let Some(color) = mode.color() {
            color
        } else {
            let color = if phase.is_multiple_of(2) {
                COLORS[phase / 2]
            } else {
                (false, false, false)
            };
            phase = (phase + 1) % (COLORS.len() * 2);
            color
        };
        led.show(color.0, color.1, color.2);
        Timer::after(Duration::from_millis(300)).await;
    }
}

#[embassy_executor::task]
async fn can_rx_task(mut rx: CanRx<'static>, own_id: u32, flash: embassy_stm32::Peri<'static, peripherals::FLASH>) {
    let flash = Mutex::<NoopRawMutex, _>::new(RefCell::new(Flash::new_blocking(flash)));
    let config = FirmwareUpdaterConfig::from_linkerfile_blocking(&flash, &flash);
    let mut aligned = [0u8; 8];
    let updater = BlockingFirmwareUpdater::new(config, &mut aligned);
    #[cfg(feature = "rev1")]
    let kind = ImageKind::DstRev1;
    #[cfg(feature = "rev2")]
    let kind = ImageKind::DstRev2;
    let max_size = if cfg!(feature = "rev1") { 240 * 1024 } else { 54 * 1024 };
    let mut update = update_receiver::Receiver::new(updater, own_id, kind, max_size);
    update.confirm_boot();
    let mut updating = false;
    loop {
        #[cfg(feature = "rev1")]
        let envelope = match select(rx.read_fd(), ERASE_REQUEST.receive()).await {
            Either::First(Ok(envelope)) => envelope,
            Either::First(Err(_)) => continue,
            Either::Second(()) => {
                // BOOT_LOCK forces main-flash boot even when EMPTY is set.
                if unsafe { core::ptr::read_volatile(0x4002_2080 as *const u32) } & (1 << 16) != 0 {
                    ERASE_RESPONSE.send(EraseResult::BootLocked).await;
                    continue;
                }
                dst_01::sync::inhibit_for_update();
                for district in &dst_01::tasks::DISTRICTS {
                    let _ = district.configure(Default::default());
                }
                Timer::after(Duration::from_millis(10)).await;
                // STM32G0B1 page 0 is 2 KiB. Erasing its first word triggers
                // the hardware empty check on option-byte reload or power-on.
                let erased = flash.lock(|flash| flash.borrow_mut().blocking_erase(0, 2048)).is_ok()
                    && unsafe { core::ptr::read_volatile(0x0800_0000 as *const u32) }
                        == 0xffff_ffff;
                if erased {
                    // EMPTY survives a software reset, so update it here too.
                    let acr = 0x4002_2000 as *mut u32;
                    unsafe {
                        core::ptr::write_volatile(
                            acr,
                            core::ptr::read_volatile(acr) | (1 << 16),
                        );
                    }
                }
                ERASE_RESPONSE.send(if erased { EraseResult::Erased } else { EraseResult::Failed }).await;
                if erased {
                    Timer::after(Duration::from_millis(200)).await;
                    cortex_m::peripheral::SCB::sys_reset();
                }
                continue;
            }
        };
        #[cfg(feature = "rev2")]
        let Ok(envelope) = rx.read_fd().await else {
            continue;
        };
        let frame = envelope.frame;
        if !frame.header().fdcan() || frame.header().rtr() {
            continue;
        }
        let embedded_can::Id::Extended(id) = frame.id() else {
            continue;
        };
        if let Some(begin) = update::Begin::decode(id.as_raw(), frame.data()) {
            if begin.target == own_id && begin.kind == kind && (8..=max_size).contains(&begin.size) {
                updating = true;
                #[cfg(feature = "rev1")]
                dst_01::sync::inhibit_for_update();
                for district in &dst_01::tasks::DISTRICTS {
                    let _ = district.configure(Default::default());
                }
                Timer::after(Duration::from_millis(10)).await;
            }
        }
        if let Some(status) = update.handle(id.as_raw(), frame.data()) {
            UPDATE_RESP.send(status).await;
            if status.phase == Phase::Rebooting {
                Timer::after(Duration::from_millis(200)).await;
                cortex_m::peripheral::SCB::sys_reset();
            }
            continue;
        }
        if updating { continue; }
        #[cfg(feature = "rev1")]
        {
            dst_01::sync::receive(id.as_raw(), frame.data(), own_id);
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

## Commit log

2026-09-27 Initial ARC KDL designs
    [dst-01x4.kicad_pcb, dst-01x6.kicad_pcb, dst-01x8.kicad_pcb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]
2026-09-27 Introduce Stackup as ARC's schematic language
2026-09-27 Add DST-01x4 firmware core and host board models
2026-09-27 Run host firmware nodes on simulated CAN bus
2026-09-29 Add deterministic CAN and physical track simulation
2026-09-29 Add local KiCad schematic inspection guide
